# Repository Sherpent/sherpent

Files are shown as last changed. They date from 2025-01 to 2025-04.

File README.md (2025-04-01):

# Sherpent – Équipe #3
## S.H.E.R.P.E.N.T.
Système
Hybride
Exploratoire
Robotique
Prototypé
Et
Navigation
Tout-terrain

## 🌐 Projet: Sherpent – Robot Tout-Terrain Inspiré des Serpents

**Membres de l'équipe :**
- **Nathan Lachapelle** (lacn1101)
- **Émile Raymond** (raye1901)
- **Gabriel Grondin** (grog1401)
- **Mathieu Durand** (durm1207)
- **Renaud Gagnon** (gegr1618)
- **Maxime Boucher** (boom0704)

---

## 🔬 Contexte

Le projet Sherpent vise à concevoir et prototyper un véhicule tout-terrain s’inspirant des mouvements ondulatoires d’un serpent pour se déplacer. Les serpents utilisent leurs centaines de vertèbres et leurs muscles pour glisser sur diverses surfaces (‎terre, bois, vitre, sable, etc.), ce qui leur confère une capacité passe-partout. Ce type de locomotion est idéal pour des missions d’exploration terrestre ou pour évoluer dans des environnements extraterrestres hostiles.

L'étude des mouvements naturels de ces reptiles servira de base à la conception du robot Sherpent.

---

## 🎯 Objectifs du Projet

- **Robot articulé :** Le robot comprendra des joints articulés permettant des mouvements ondulatoires.
- **Actionneurs et capteurs :** Intégration d’actionneurs et de capteurs pour permettre un contrôle précis des mouvements.
- **Contrôle autonome :** Le robot fonctionnera de manière autonome, sans dépendance à des fils ou sources externes.
- **Langage Python :** Utilisation de Python pour une partie du code contrôlant le robot.
- **Applications potentielles :** Exploration terrestre ou exploration d’environnements extraterrestres.

---

## 📅 Livrables Attendues
Le projet sera développé en utilisant la méthodologie Agile, avec des livrables majeurs prévus à la fin de chaque sprint de 3 semaines :

| **Dates** | **Livrables Importants** |
|---|---|
| 22 janvier 2025 | Preuve de concept simple |
| 12 février 2025 | PCB montés et débuggés |
| 26 février 2025 | Contrôle du prototype |
| 26 mars 2025 | Phase de test du prototype |
| 11 avril 2025 | Rapport et prototype final |

---

## 📊 Analyse Sommaire de Faisabilité

**Compétences :** L’équipe possède une expertise multidisciplinaire en robotique :
- Compétences en électronique, mécanique et informatique.

**Ressources matérielles :** 
- Accès à du matériel et des installations telles que machines-outils, composants électroniques, et équipements de prototypage.

**Budget :** Les coûts supplémentaires seront partagés ou répartis selon les membres qui conserveront les matériaux au terme du projet.

**Conclusion :** Compte tenu des compétences, du matériel disponible et des ressources temporelles, l’équipe juge ce projet réalisable dans les délais impartis.

---

## 🔄 Planification Sommaire

1. **Organisation de l’équipe :**
   - Division en trois sections : électrique, mécanique, et informatique.
   - Collaboration interdépendante pour surmonter les embûches.

2. **Gestion de Projet :**
   - Utilisation de GitHub pour gérer le code, les fichiers, et la planification.
   - Réunion hebdomadaire chaque mercredi pour faire le point sur les avancements et problèmes.

3. **Développement Agile :**
   - Livrables précis à la fin de chaque sprint de 3 semaines.

---

## 🔧 Utilisation de GitHub

1. **Structure du Répertoire :**
   ```
   Sherpent/
   ├── elec/       # Fichiers électroniques (PCB, schémas, etc.)
   ├── mec/        # Fichiers mécaniques (CAD, modèles 3D, etc.)
   ├── code/       # Fichiers de code (Python, firmware, etc.)
   └── docs/       # Documentation et rapports
   ```

2. **Outils GitHub :**
   - **Issues :** Pour suivre les problèmes et défis.
   - **Projets :** Pour gérer les tâches et la planification Agile.
   - **Pull Requests :** Pour réviser et intégrer les changements.

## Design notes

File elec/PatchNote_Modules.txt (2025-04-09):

Patch notes

Pcb #1 État: Testé bat + moteurs
	Problème:
	Rien ne se passe quand no appuie sur le bouton.
	Avec USB: S'allume quand on pese sur le bouton (D25 manquante)
		Apres avoir été pluggé, le bouton fais allumer meme sur betterie mais stayon marche pas
	Avec safety bypass: Ya juste le stayon qui marche pas
	Mesures:
	Pin stayon tjrs à 0v
	
	Solution: 
		Changer le code
		Patch temporaire: Brancher usb pour sortir de over current protection
		Patch long terme: Betteries plus chargées? Bypasser le board bleu?
	C'est réglé.
	Problème: Board bleu laisse pas poweron après avoir branché la batterie. Il faut plugger usb ou short b-

PCB#2 État: Testé bat+moteurs

PCB#3 État: Testé bat + moteurs
	Problème: ne s'allume pas
	Mesures: 
		- Sortie du boost quand on pese sur le bouton: 2.8v
		- EN du boost tjrs a 0v
	Solution short en a 1 sur footprint de Q4
	Résultat: Fonctionne bien. À tester avec moteurs

PCB#4 État: Testé bat + moteurs
	Problème: Gate du power mosfet est tjrs triggered par tension sur vusb causée par le board bleu car il a une diode ordinaire et non une led
	Solution: Mettre une led sur D25 pour drop de tension plus haute (les autres pcbs l'ont deja)

PCB#5 État: En cours de soudure

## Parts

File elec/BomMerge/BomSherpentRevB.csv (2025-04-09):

Reference | Value | Footprint | Qty | DigiKey
BT1,BT2 | Battery_Cell | Connector_PinHeader_2.54mm:PinHeader_1x02_P2.54mm_Vertical | 2
C2,C15,C16 | 10u | Capacitor_SMD:C_0603_1608Metric_Pad1.08x0.95mm_HandSolder | 3 | 587-1256-1-ND
C3,C5,C21 | 100n | Capacitor_SMD:C_0603_1608Metric_Pad1.08x0.95mm_HandSolder | 3 | 311-1344-1-ND
C7,C8 | 100u | Capacitor_THT:CP_Radial_D5.0mm_P2.00mm | 2 | 732-8793-1-ND
C9,C10 | 1u | Capacitor_SMD:C_0603_1608Metric_Pad1.08x0.95mm_HandSolder | 2 | 587-1248-1-ND
C11 | 39n | Capacitor_SMD:C_0603_1608Metric_Pad1.08x0.95mm_HandSolder | 1 | 1276-2055-1-ND
C12 | 100p | Capacitor_SMD:C_0603_1608Metric_Pad1.08x0.95mm_HandSolder | 1 | 490-4771-1-ND
C13,C31,C32,C33 | 47u | Capacitor_SMD:C_0603_1608Metric_Pad1.08x0.95mm_HandSolder | 4 | 1276-1852-1-ND
C17,C26 | 0.1u | Capacitor_SMD:C_0603_1608Metric_Pad1.08x0.95mm_HandSolder | 2 | 311-1344-1-ND
C30 | 100u | Capacitor_SMD:C_0603_1608Metric_Pad1.08x0.95mm_HandSolder | 1 | 490-GRM21BR60G107ME11KCT-ND
D3,D4,D5,D13 | SS14 | Diode_SMD:D_SMA | 4 | SS14CT-ND
D7,D8,D9,D10,D11,D12,D16,D17,D18,D19 | WS2812B | LED_SMD:LED_WS2812B_PLCC4_5.0x5.0mm_P3.2mm | 10
F2,F3 | 10A | Fuse:Fuse_0603_1608Metric | 2 | 5923-0686F8000-01CT-ND
J1 | 2137160001 | 2137160001:MOLEX_2137160001 | 1 | 2073-USB4085-GF-ACT-ND
J2,J3,J4 | Conn_01x03_Socket | Connector_PinHeader_2.54mm:PinHeader_1x03_P2.54mm_Vertical | 3
JP7 | BOOT | Connector_PinHeader_2.54mm:PinHeader_1x02_P2.54mm_Vertical | 1
L1 | 1.2u | CMLE105T-2R2MS:IND_CMLE105T-1R0&slash_1R5&slash_2R2_CYN | 1 | 2037-CMLE105T-1R0MSCT-ND
Q1,Q5,Q6 | PMOS | Package_TO_SOT_SMD:SOT-223 | 3 | 3141-G170P06MCT-ND
Q2,Q3 | Q_NMOS_GSD | Package_TO_SOT_SMD:SOT-23 | 2 | 448-SN7002NH6433XTMA1CT-ND
R1,R3,R5,R6,R9,R16,R19,R20,R21,R22 | 10k | Resistor_SMD:R_0603_1608Metric | 10 | 311-5.10KHRCT-ND
R4,R10 | 5.1k | Resistor_SMD:R_0603_1608Metric | 2 | 311-5.10KHRCT-ND
R11 | 45.3k | Resistor_SMD:R_0603_1608Metric | 1 | 311-45.3KHRCT-ND
R12 | 357k | Resistor_SMD:R_0603_1608Metric | 1 | 311-357KHRCT-ND
R13 | 48.7k | Resistor_SMD:R_0603_1608Metric | 1 | 311-48.7KHRCT-ND
R17 | 0 | Resistor_SMD:R_0603_1608Metric | 1 | 311-0.0GRCT-ND
R27 | 50k | Resistor_SMD:R_0603_1608Metric | 1 | 13-RT0603BRD0750KLCT-ND
R28 | 100k 1% | Resistor_SMD:R_0603_1608Metric | 1 | P100KHCT-ND
SW1 | CT1102 | CT1102V3.15F100:CT1102V3.15F100 | 1 | 2449-CT1102V3.15F100-ND
SW2 | RESET | CS1213AGF160:SW_CS1213AG_CRS | 1 | 2449-CS1213AGF260CT-ND
SW3 | BOOT | CS1213AGF160:SW_CS1213AG_CRS | 1 | 2449-CS1213AGF260CT-ND
TP2 | VUSB | TestPoint:TestPoint_Loop_D2.54mm_Drill1.5mm_Beaded | 1
TP3 | RX | TestPoint:TestPoint_Loop_D2.54mm_Drill1.5mm_Beaded | 1
TP4 | 3v3 | TestPoint:TestPoint_Loop_D2.54mm_Drill1.5mm_Beaded | 1
TP5 | TX | TestPoint:TestPoint_Loop_D2.54mm_Drill1.5mm_Beaded | 1
TP6,TP8,TP16 | GND | TestPoint:TestPoint_Loop_D2.54mm_Drill1.5mm_Beaded | 3
TP7 | V_D | TestPoint:TestPoint_Loop_D2.54mm_Drill1.5mm_Beaded | 1
TP9 | NEO | TestPoint:TestPoint_Loop_D2.54mm_Drill1.5mm_Beaded | 1
TP10 | B+ | TestPoint:TestPoint_Loop_D2.54mm_Drill1.5mm_Beaded | 1
TP11 | B- | TestPoint:TestPoint_Loop_D2.54mm_Drill1.5mm_Beaded | 1
TP12 | PWM1 | TestPoint:TestPoint_Loop_D2.54mm_Drill1.5mm_Beaded | 1
TP13 | PWM2 | TestPoint:TestPoint_Loop_D2.54mm_Drill1.5mm_Beaded | 1
TP14,TP15 | V_B | TestPoint:TestPoint_Loop_D2.54mm_Drill1.5mm_Beaded | 2
TP17 | ST | TestPoint:TestPoint_Loop_D2.54mm_Drill1.5mm_Beaded | 1
U1 | TPD2EUSB30 | Package_TO_SOT_SMD:Texas_DRT-3 | 1 | 296-28153-1-ND
U2 | TPS61288LRQQR | TPS61288LRQQR:RQQ0011A-MFG | 1 | 296-TPS61288LRQQRCT-ND
U3 | LM66200DRLR | LM66200DRLR:SOT-5X3_DRL_TEX-L | 1 | 296-LM66200DRLRCT-ND
U4 | TP4056 | TP4056:TP4056-18650 | 1
U5 | LD1117S33TR_SOT223 | Package_TO_SOT_SMD:SOT-223-3_TabPin2 | 1 | 497-1241-1-ND
U8 | ESP32-C3-WROOM-02 | RF_Module:ESP32-C3-WROOM-02 | 1 | 1965-ESP32-C3-WROOM-02-N4CT-ND

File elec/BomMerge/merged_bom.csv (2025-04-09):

Reference | Value | Footprint | Qty | DigiKey | Datasheet
1C20 | 10u | Capacitor_SMD:C_0402_1005Metric_Pad0.74x0.62mm_HandSolder | 1 | 1276-1450-1-ND | ~
C13,C31,C32,C33 | 47u | Capacitor_SMD:C_0603_1608Metric_Pad1.08x0.95mm_HandSolder | 4 | 1276-1852-1-ND
C11 | 39n | Capacitor_SMD:C_0603_1608Metric_Pad1.08x0.95mm_HandSolder | 1 | 1276-2055-1-ND
R27 | 50k | Resistor_SMD:R_0603_1608Metric | 1 | 13-RT0603BRD0750KLCT-ND
1U7 | ESP32-C3 | ESP32_C3:QFN32_5X5_EXP-L | 1 | 1904-ESP32-C3FH4CT-ND | ESP32-C3
U8 | ESP32-C3-WROOM-02 | RF_Module:ESP32-C3-WROOM-02 | 1 | 1965-ESP32-C3-WROOM-02-N4CT-ND
L1 | 1.2u | CMLE105T-2R2MS:IND_CMLE105T-1R0&slash_1R5&slash_2R2_CYN | 1 | 2037-CMLE105T-1R0MSCT-ND
J1 | 2137160001 | 2137160001:MOLEX_2137160001 | 1 | 2073-USB4085-GF-ACT-ND
SW3 | BOOT | CS1213AGF160:SW_CS1213AG_CRS | 1 | 2449-CS1213AGF260CT-ND
SW1 | CT1102 | CT1102V3.15F100:CT1102V3.15F100 | 1 | 2449-CT1102V3.15F100-ND
U1 | TPD2EUSB30 | Package_TO_SOT_SMD:Texas_DRT-3 | 1 | 296-28153-1-ND
U3 | LM66200DRLR | LM66200DRLR:SOT-5X3_DRL_TEX-L | 1 | 296-LM66200DRLRCT-ND
U2 | TPS61288LRQQR | TPS61288LRQQR:RQQ0011A-MFG | 1 | 296-TPS61288LRQQRCT-ND
1R21,R26 | 0 | Resistor_SMD:R_0603_1608Metric | 2 | 311-0.0GRCT-ND | ~
1C3,C5,C17,C21,C24 | 100n | Capacitor_SMD:C_0603_1608Metric_Pad1.08x0.95mm_HandSolder | 5 | 311-1344-1-ND | ~
1C23 | 100n | Capacitor_SMD:C_0402_1005Metric_Pad0.74x0.62mm_HandSolder | 1 | 311-3566-1-ND | ~
R12 | 357k | Resistor_SMD:R_0603_1608Metric | 1 | 311-357KHRCT-ND
R11 | 45.3k | Resistor_SMD:R_0603_1608Metric | 1 | 311-45.3KHRCT-ND
R13 | 48.7k | Resistor_SMD:R_0603_1608Metric | 1 | 311-48.7KHRCT-ND
R1,R3,R5,R6,R9,R16,R19,R20,R21,R22 | 10k | Resistor_SMD:R_0603_1608Metric | 10 | 311-5.10KHRCT-ND
Q1,Q5,Q6 | PMOS | Package_TO_SOT_SMD:SOT-223 | 3 | 3141-G170P06MCT-ND
Q2,Q3 | Q_NMOS_GSD | Package_TO_SOT_SMD:SOT-23 | 2 | 448-SN7002NH6433XTMA1CT-ND
1C25 | 1u | Capacitor_SMD:C_0402_1005Metric_Pad0.74x0.62mm_HandSolder | 1 | 490-10024-1-ND | ~
1L2 | 2.7n | Inductor_SMD:L_0402_1005Metric_Pad0.77x0.64mm_HandSolder | 1 | 490-1078-1-ND | ~
1L3 | 2n | Inductor_SMD:L_0402_1005Metric_Pad0.77x0.64mm_HandSolder | 1 | 490-15076-1-ND | ~
1C6 | 2.2u | Capacitor_SMD:C_0603_1608Metric_Pad1.08x0.95mm_HandSolder | 1 | 490-4520-1-ND | ~
C12 | 100p | Capacitor_SMD:C_0603_1608Metric_Pad1.08x0.95mm_HandSolder | 1 | 490-4771-1-ND
1C19,C26 | 10n | Capacitor_SMD:C_0603_1608Metric_Pad1.08x0.95mm_HandSolder | 2 | 490-4781-1-ND | ~
1C16,C18 | 1.8p | Capacitor_SMD:C_0402_1005Metric_Pad0.74x0.62mm_HandSolder | 2 | 490-6215-1-ND | ~
1C27,C28 | 15p | Capacitor_SMD:C_0402_1005Metric_Pad0.74x0.62mm_HandSolder | 2 | 490-8080-1-ND | ~
C30 | 100u | Capacitor_SMD:C_0603_1608Metric_Pad1.08x0.95mm_HandSolder | 1 | 490-GRM21BR60G107ME11KCT-ND
U5 | LD1117S33TR_SOT223 | Package_TO_SOT_SMD:SOT-223-3_TabPin2 | 1 | 497-1241-1-ND
1Y1 | 40MHz | 830059627:SMD_059627_WRE-L | 1 | 535-15013-1-ND | ~
1C9,C10,C22,C29 | 1u | Capacitor_SMD:C_0603_1608Metric_Pad1.08x0.95mm_HandSolder | 4 | 587-1248-1-ND | ~
C2,C15,C16 | 10u | Capacitor_SMD:C_0603_1608Metric_Pad1.08x0.95mm_HandSolder | 3 | 587-1256-1-ND
1F2,F3 | 10A | Fuse:Fuse_0603_1608Metric | 2 | 5923-0686F8000-01CT-ND | ~
1C7,C8 | 100u | Capacitor_THT:CP_Radial_D5.0mm_P2.00mm | 2 | 732-8793-1-ND | ~
1R24 | 0 | Resistor_SMD:R_0402_1005Metric_Pad0.72x0.64mm_HandSolder | 1 | P0.0JCT-ND | ~
R28 | 100k 1% | Resistor_SMD:R_0603_1608Metric | 1 | P100KHCT-ND
D3,D4,D5,D13 | SS14 | Diode_SMD:D_SMA | 4 | SS14CT-ND
1D1,D2,D25 | D_Schottky | LED_SMD:LED_0603_1608Metric_Pad1.05x0.95mm_HandSolder | 3 | TSS54URGGCT-ND | ~
D7,D8,D9,D10,D11,D12,D16,D17,D18,D19 | WS2812B | LED_SMD:LED_WS2812B_PLCC4_5.0x5.0mm_P3.2mm | 10

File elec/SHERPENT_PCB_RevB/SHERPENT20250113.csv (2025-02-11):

Id | Designator | Footprint | Quantity | Designation | Supplier and ref
1 | R24 | R_0402_1005Metric_Pad0.72x0.64mm_HandSolder | 1 | 0
2 | D9,D8,D17,D10,D16,D18,D19,D12,D7,D11 | LED_WS2812B_PLCC4_5.0x5.0mm_P3.2mm | 10 | WS2812B
3 | C12 | C_0603_1608Metric_Pad1.08x0.95mm_HandSolder | 1 | 100p
4 | D2,D25,D1 | LED_0603_1608Metric_Pad1.05x0.95mm_HandSolder | 3 | D_Schottky
5 | R9,R1,R20,R17,R22,R5,R16,R6,R3,R25 | R_0603_1608Metric | 10 | 10k
6 | Q4,Q2 | SOT-23 | 2 | PMOS
7 | D3,D6 | LED_0603_1608Metric_Pad1.05x0.95mm_HandSolder | 2 | LED
8 | C25 | C_0402_1005Metric_Pad0.74x0.62mm_HandSolder | 1 | 1u
9 | C3,C14,C21,C17,C24 | C_0603_1608Metric_Pad1.08x0.95mm_HandSolder | 5 | 100n
10 | C4,C1 | C_0603_1608Metric_Pad1.08x0.95mm_HandSolder | 2 | 4.7u
11 | C5 | C_0603_1608Metric_Pad1.08x0.95mm_HandSolder | 1 | 100nf
12 | C29,C10,C9,C22 | C_0603_1608Metric_Pad1.08x0.95mm_HandSolder | 4 | 1u
13 | R2,R14 | R_0603_1608Metric | 2 | 100k
14 | R18,R26,R21 | R_0603_1608Metric | 3 | 0
15 | C16,C18 | C_0402_1005Metric_Pad0.74x0.62mm_HandSolder | 2 | 1.8p
16 | C23 | C_0402_1005Metric_Pad0.74x0.62mm_HandSolder | 1 | 100n
17 | TP1 | TestPoint_Loop_D2.54mm_Drill1.5mm_Beaded | 1 | VBATT
18 | J4,J2,J3 | PinHeader_1x03_P2.54mm_Vertical | 3 | Conn_01x03_Socket
19 | R10,R4 | R_0603_1608Metric | 2 | 5.1k
20 | L2 | L_0402_1005Metric_Pad0.77x0.64mm_HandSolder | 1 | 2.7n
21 | R13 | R_0603_1608Metric | 1 | 48.7k
22 | R11 | R_0603_1608Metric | 1 | 45.3k
23 | TP7,NEO-END1,TP4,TP2 | TestPoint_Loop_D2.54mm_Drill1.5mm_Beaded | 4 | TestPoint
24 | C11 | C_0603_1608Metric_Pad1.08x0.95mm_HandSolder | 1 | 39n
25 | F3,F2 | Fuse_0603_1608Metric | 2 | 10A
26 | C20 | C_0402_1005Metric_Pad0.74x0.62mm_HandSolder | 1 | 10u
27 | L3 | L_0402_1005Metric_Pad0.77x0.64mm_HandSolder | 1 | 2n
28 | C30 | C_0603_1608Metric_Pad1.08x0.95mm_HandSolder | 1 | 100u
29 | U6 | AN034_ANTENNA | 1 | AN034_ANTENNA
30 | C8,C7 | CP_Radial_D5.0mm_P2.00mm | 2 | 100u
31 | C28,C27 | C_0402_1005Metric_Pad0.74x0.62mm_HandSolder | 2 | 15p
32 | Q3,Q1 | SOT-23 | 2 | NMOS
33 | C15,C2 | C_0603_1608Metric_Pad1.08x0.95mm_HandSolder | 2 | 10u
34 | D28,D4 | R_0603_1608Metric_Pad0.98x0.95mm_HandSolder | 2 | D_Zener
35 | R7 | R_0603_1608Metric | 1 | 470
36 | C26,C19 | C_0603_1608Metric_Pad1.08x0.95mm_HandSolder | 2 | 10n
37 | BT1,BT2 | PinHeader_1x02_P2.54mm_Vertical | 2 | Battery_Cell
38 | D29 | D_0603_1608Metric_Pad1.05x0.95mm_HandSolder | 1 | D
39 | U2 | RQQ0011A-MFG | 1 | TPS61288LRQQR
40 | R28 | R_0603_1608Metric | 1 | 100k 1%
41 | R12 | R_0603_1608Metric | 1 | 357k
42 | R23 | R_0603_1608Metric | 1 | 130
43 | U5 | SOT-223-3_TabPin2 | 1 | LD1117S33TR_SOT223
44 | C13 | C_0603_1608Metric_Pad1.08x0.95mm_HandSolder | 1 | 47u
45 | C6 | C_0603_1608Metric_Pad1.08x0.95mm_HandSolder | 1 | 2.2u
46 | SW2 | SW_CS1213AG_CRS | 1 | SW_Push
47 | R8 | R_0603_1608Metric | 1 | 2k
48 | J1 | MOLEX_2137160001 | 1 | 2137160001
49 | R27 | R_0603_1608Metric | 1 | 50k
50 | JP19 | TestPoint_2Pads_Pitch2.54mm_Drill0.8mm | 1 | Jumper_2_Bridged
51 | Y1 | SMD_059627_WRE-L | 1 | 40MHz
52 | L1 | L_0603_1608Metric | 1 | 1.2u
53 | U7 | QFN32_5X5_EXP-L | 1 | ESP32-C3
54 | U1 | SOT95P280X145-5N | 1 | MCP73831T-2ACI_OT
55 | U4 | TP4056-18650 | 1 | TP4056
56 | SW1 | CT1102V3.15F100 | 1 | CT1102
57 | D27,D26 | SOT-23 | 2 | BAV99

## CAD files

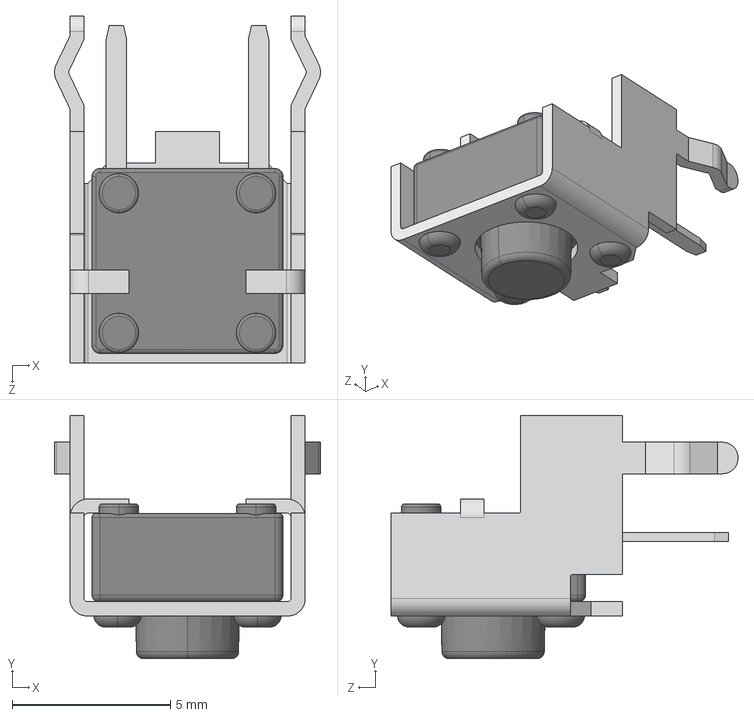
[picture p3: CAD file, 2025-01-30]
elec/SHERPENT_PCB_RevB/Librairie/CT1102V3.15F100/CT1102V3.85F160.stp
8.42 x 7.70 x 11.0 mm

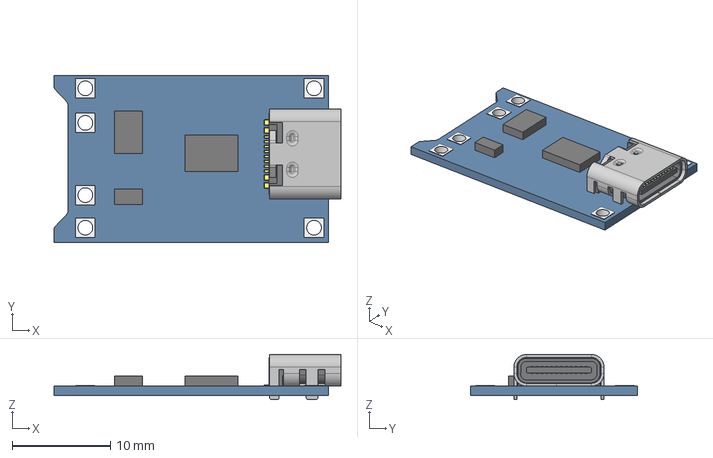
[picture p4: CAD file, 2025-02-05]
elec/SHERPENT_PCB_RevB/Librairie/TP4056/TP4056--3DModel-STEP-684600.STEP
29.3 x 17.0 x 4.60 mm

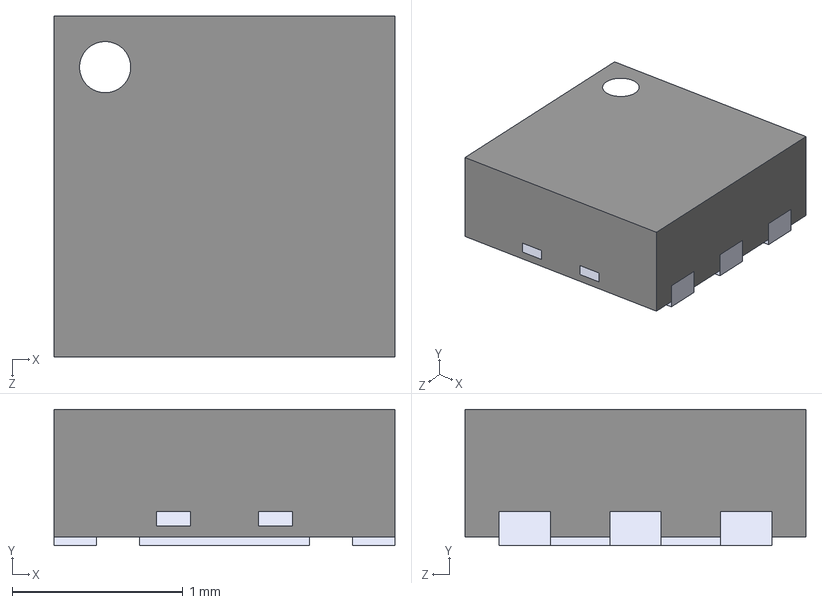
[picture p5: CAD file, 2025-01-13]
elec/SHERPENT_PCB_RevB/Librairie/TPS7A2633DRVR/TPS7A2633DRVR.step
2.00 x 0.8 x 2.00 mm

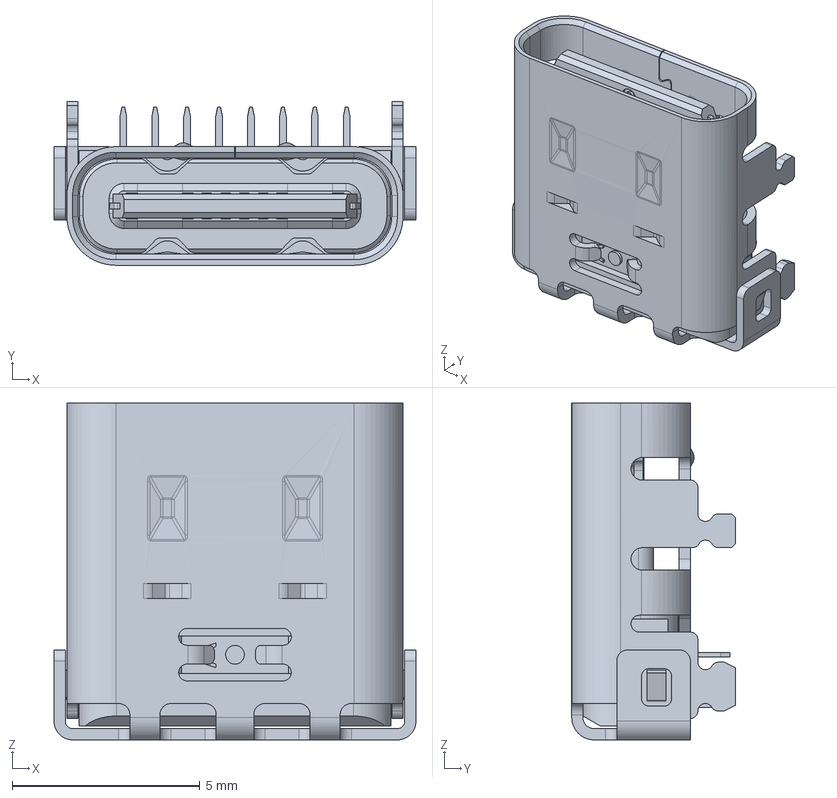
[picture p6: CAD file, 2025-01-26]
elec/SHERPENT_PCB_RevB/Librairie/2137160001/2137160001.stp
9.64 x 4.36 x 8.97 mm

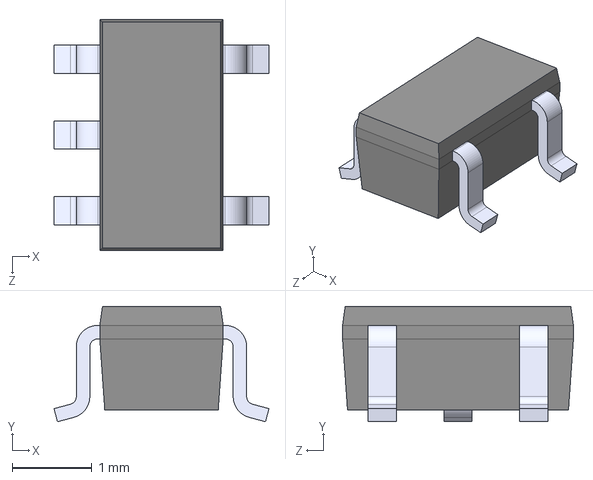
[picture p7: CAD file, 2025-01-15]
elec/SHERPENT_PCB_RevB/Librairie/MCP73831T_2ACI_OT/MCP73831T-2ACI_OT.step
2.70 x 1.45 x 2.90 mm

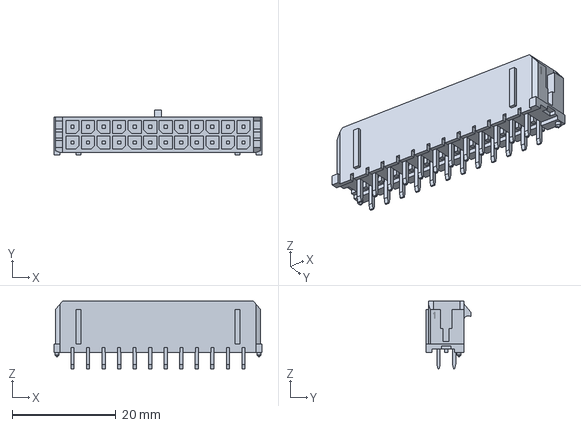
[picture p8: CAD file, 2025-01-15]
elec/SHERPENT_PCB_RevB/Librairie/MOLEX_430452428/0430452428.stp
40.1 x 8.77 x 13.1 mm

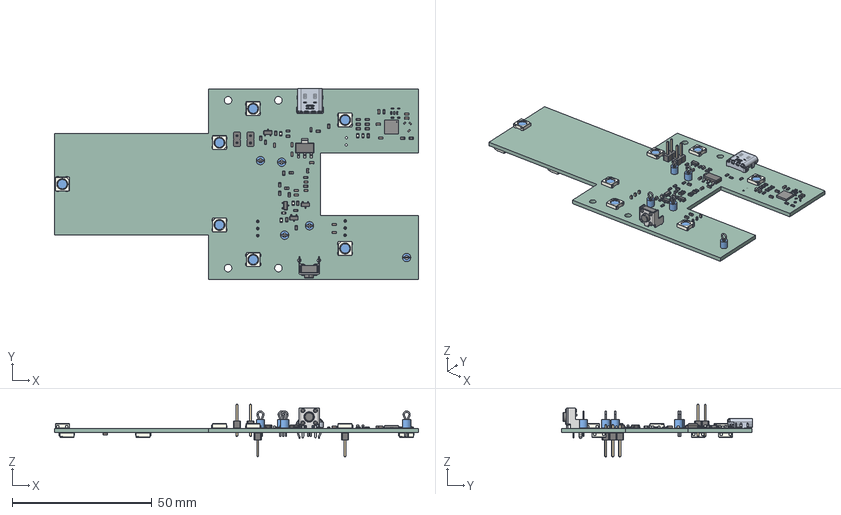
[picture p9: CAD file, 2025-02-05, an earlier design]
elec/SHERPENT_PCB_RevA/SHERPENT20250113_3.step
130.2 x 68.3 x 18.8 mm
R_0402_1005Metric
LED_WS2812B_PLCC4_50x50mm_P32mm x 13
C_0603_1608Metric x 20
LED_0603_1608Metric x 6
R_0603_1608Metric x 26
SOT_23 x 4
C_0402_1005Metric x 7
Fuse_0603_1608Metric
TestPoint_Loop_D2_54mm_Drill1_5mm_Beaded_cp x 5
L_0402_1005Metric x 2
PinHeader_1x02_P254mm_Vertical x 2
SOT_223
L_0603_1608Metric
ESP32-C3FH4
CT1102V3.85F160
PinHeader_1x03_P254mm_Vertical x 2
_autosave-SHERPENT20250113_PCB

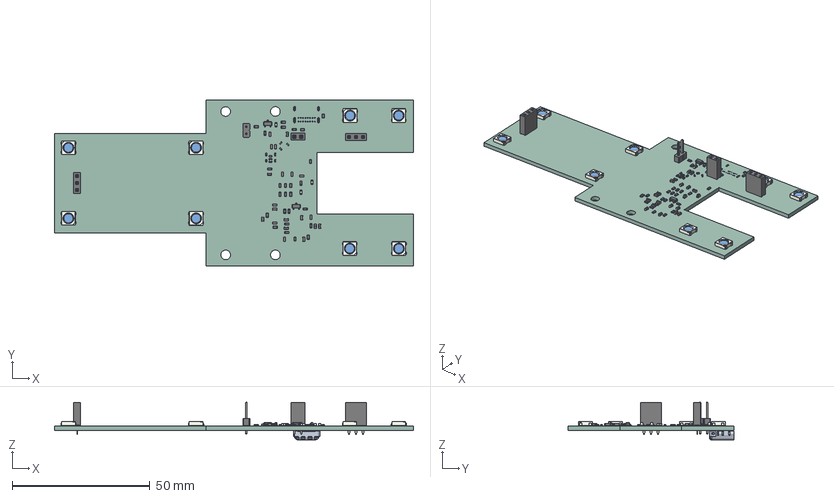
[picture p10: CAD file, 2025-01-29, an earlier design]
elec/SHERPENT_PCB_RevA/SHERPENT20250113_2.step
130.2 x 60.3 x 13.7 mm
R_0402_1005Metric
D_0603
LED_WS2812B_PLCC4_50x50mm_P32mm x 8
C_0603_1608Metric x 18
R_0603_1608Metric x 33
LED_0603_1608Metric x 3
C_0402_1005Metric x 7
Fuse_0603_1608Metric
L_0402_1005Metric x 2
SOT_23 x 2
PinHeader_1x02_P254mm_Vertical
PinSocket_1x03_P2.54mm_Vertical x 2
PinSocket_1x02_P2.54mm_Vertical
L_0603_1608Metric
SHERPENT20250113_PCB

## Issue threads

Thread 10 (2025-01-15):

Commander les pieces pour les PCB supplémentaires

gabgron, 2025-01-15:

Pinox64, 2025-04-09:
Commander pour faire 5 revB ou 2 revA (si les pcb arrivent trop tard)
Mettre les 2 boms ensemble et prendre les quantités les plus hautes (ne pas additionner)

Closed 2025-04-10.

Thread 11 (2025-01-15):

Magasinner les servos

gabgron, 2025-01-15:
Vérifier si l'école fournit des servos. Si non en acheter

gabgron, 2025-01-15:
ces servos la semblent pas-pire [lien](https://ca.robotshop.com/products/mg995-micro-servo-motor-rc-servo-20-kg-metal-gear-servo-4x) on va attndre de voir si l'ecole nous en prete

gabgron, 2025-01-15:
on va commeder sur la [lien](https://www.amazon.com/4-Pack-MG996R-Torque-Digital-Helicopter/dp/B0BMM1G74B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)

Closed 2025-01-15.

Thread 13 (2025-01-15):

Faire approver les battrie

gabgron, 2025-01-15:

maximeboucher5, 2025-01-31:
Alexandre Tessier nous a donner le go. Il va falloir faire un plan de test/procédure et avoir une autre rencontre avec lui. Le circuit à passer la "validation"

Closed 2025-01-31.

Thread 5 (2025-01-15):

Printer les bracket pour relier les servo

gabgron, 2025-01-15:

gabgron, 2025-01-15:
premier proto de fait, mais les brakets de fittent pas avec les servos qu'on a

nathan477, 2025-01-15:
Pour faire fitter les servo, on va limer les brackets (éviter de reprint les brackets)

Closed 2025-01-22.

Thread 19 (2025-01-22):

Livrer le suivi de projet avec tableau de bord (29 janvier)

nathan477, 2025-01-22:
Scrum tenu pour faire le suivi de projet (qui a fait quoi durant le dernier sprint). Tableau de bord à déposer (maximum la veille de la période de projet) pour animer la rencontre (1 page max).
Requis :
- Nom du projet et d'équipe
- Photos des membres avec leur noms et responsabilités
- Période couverte pour les activités du tableau de bord
- Objectif du projet (sommaire, maximum deux lignes)
- Suivi de projet (Burndown chart (chart, release), tâches accomplie durant la semaine, tâche à faire next week)
- Sommaire des heures de la semaine et en moyenne faites par chaque membre
- Suivi des risques avec les moyens pour les annuler/atténuer
- Problèmes rencontrés
- Points à aborder avec le superviseur de projet

nathan477, 2025-01-22:
Le template du document de suivi de projet est disponible dans le Teams sous Fichiers, General, Documents_livrable, Suivi_de_projet_template

Closed 2025-01-29.

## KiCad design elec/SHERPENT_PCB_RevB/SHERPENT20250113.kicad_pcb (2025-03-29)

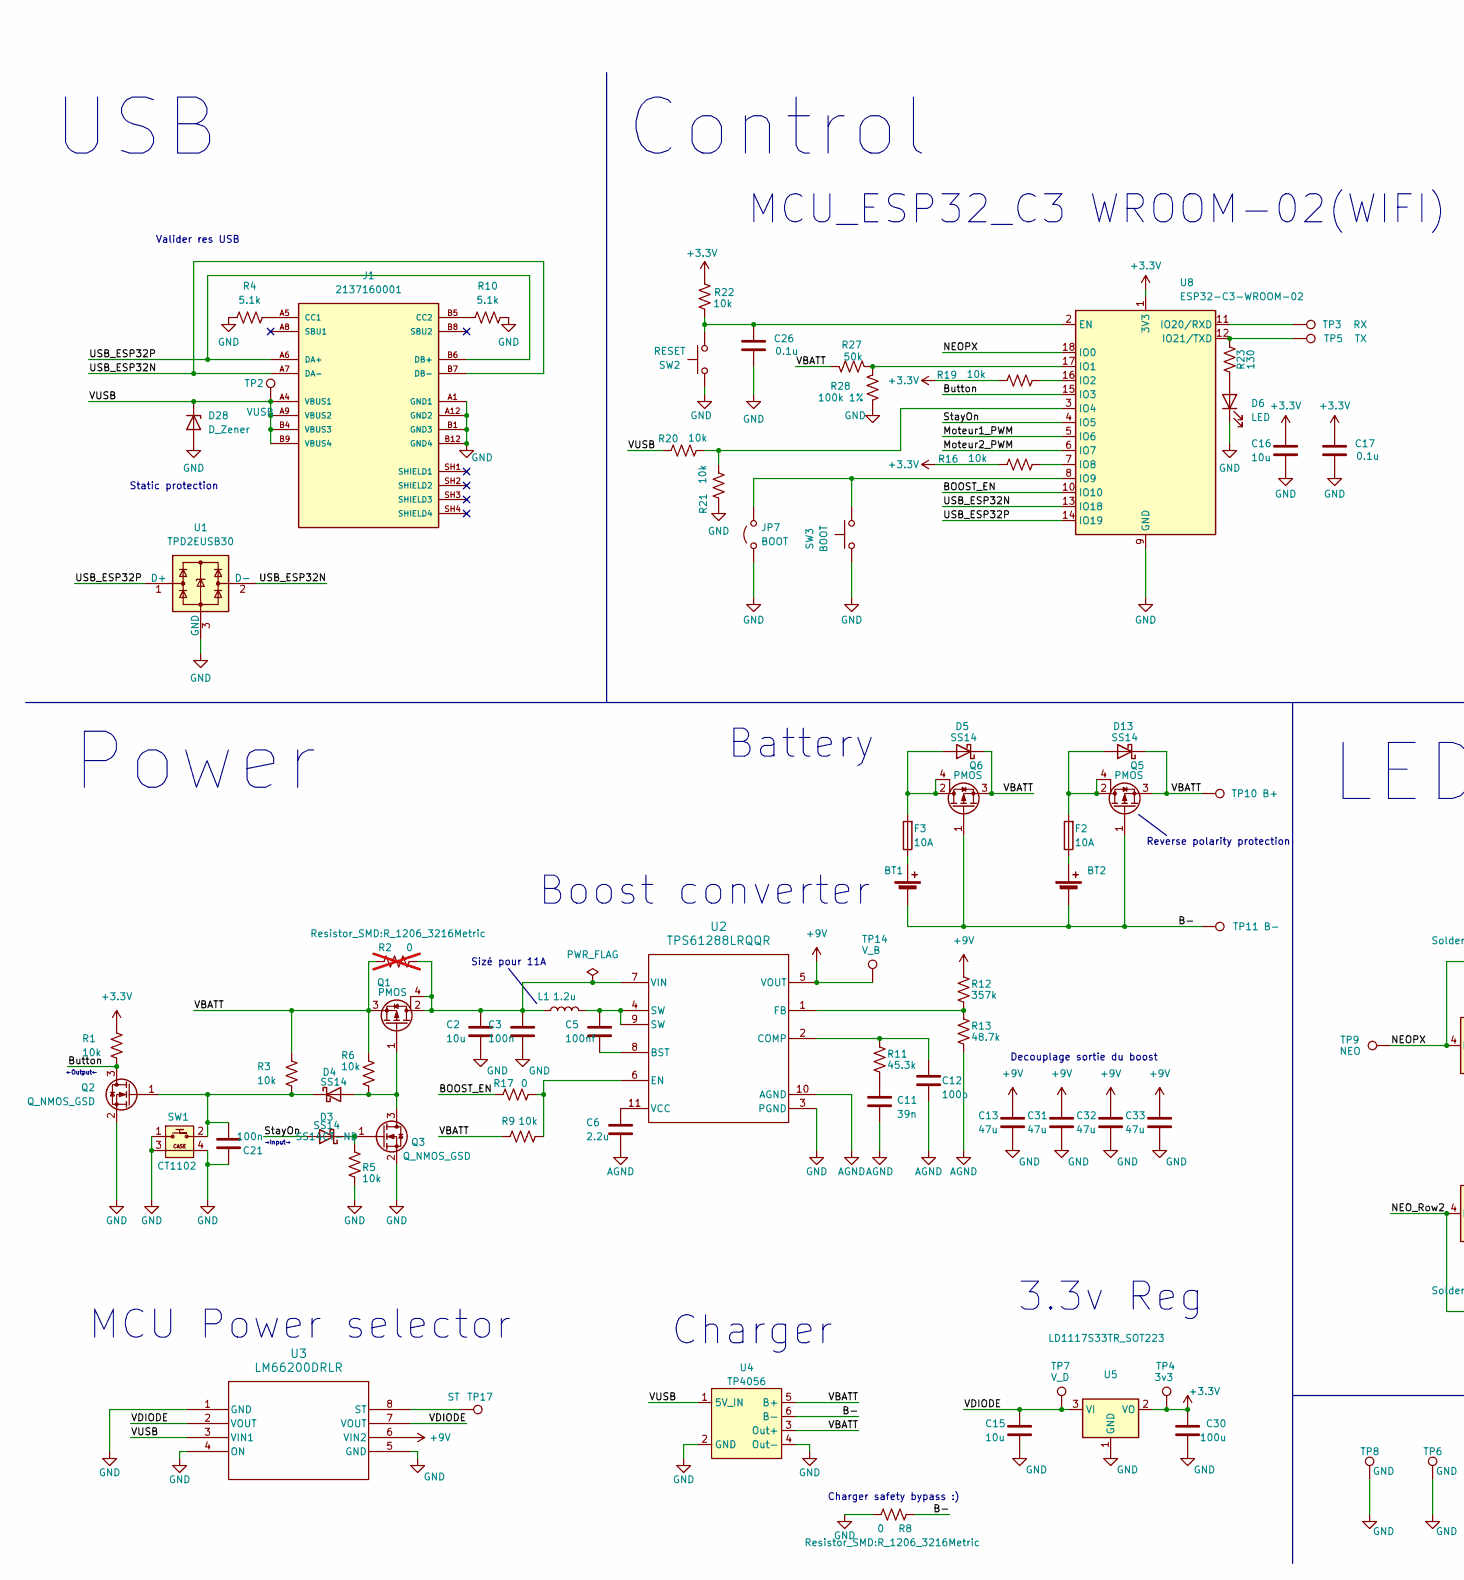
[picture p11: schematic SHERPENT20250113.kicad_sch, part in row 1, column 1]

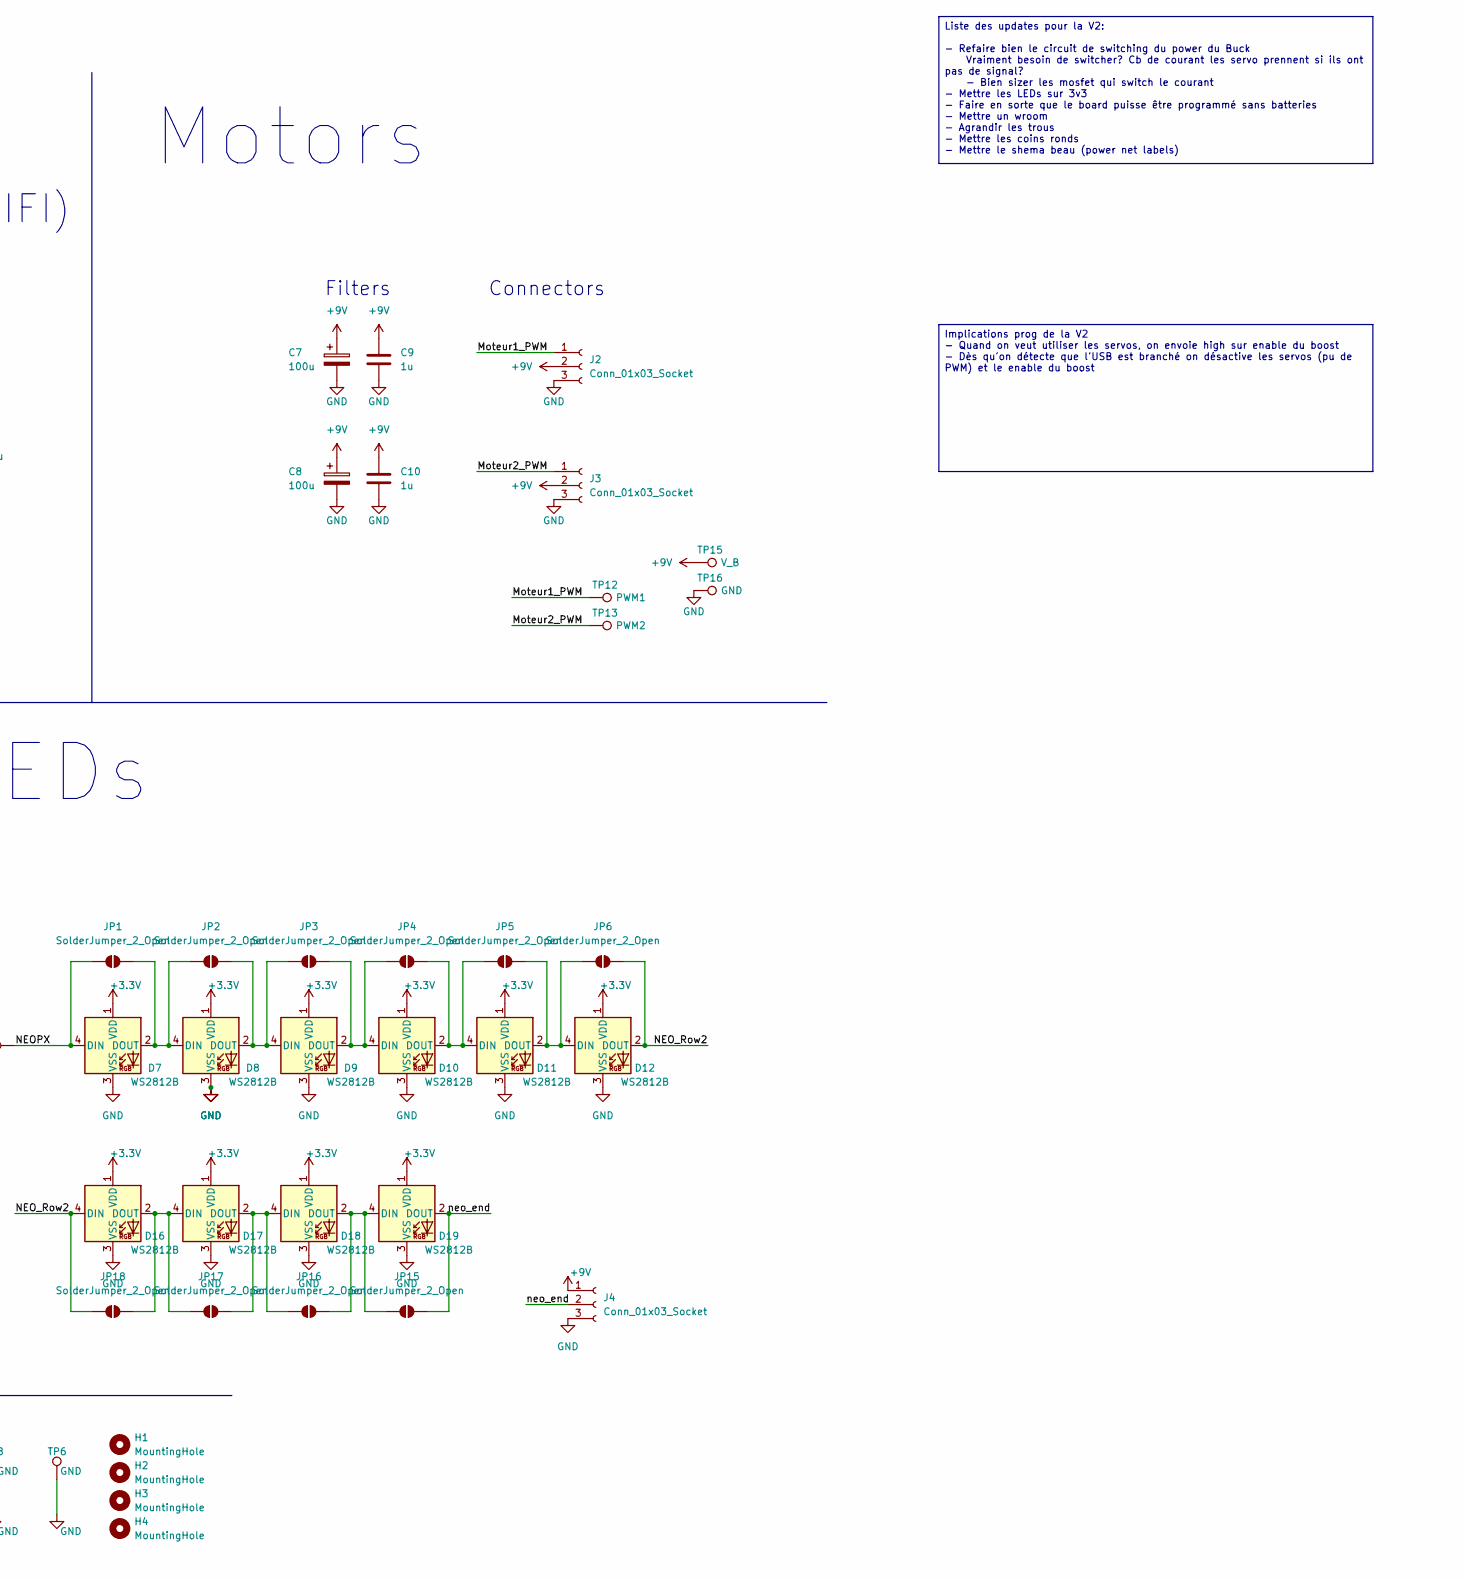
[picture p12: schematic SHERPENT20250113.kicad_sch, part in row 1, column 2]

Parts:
BT1, BT2: Battery_Cell; PinHeader_1x02_P2.54mm_Vertical
C2, C15, C16: 10u; C_0603_1608Metric_Pad1.08x0.95mm_HandSolder
C3, C21: 100n; C_0603_1608Metric_Pad1.08x0.95mm_HandSolder
C5: 100nf; C_0603_1608Metric_Pad1.08x0.95mm_HandSolder
C6: 2.2u; C_0603_1608Metric_Pad1.08x0.95mm_HandSolder
C7, C8: 100u; CP_Radial_D5.0mm_P2.00mm
C9, C10: 1u; C_0603_1608Metric_Pad1.08x0.95mm_HandSolder
C11: 39n; C_0603_1608Metric_Pad1.08x0.95mm_HandSolder
C12: 100p; C_0603_1608Metric_Pad1.08x0.95mm_HandSolder
C13, C31, C32, C33: 47u; C_0603_1608Metric_Pad1.08x0.95mm_HandSolder
C17, C26: 0.1u; C_0603_1608Metric_Pad1.08x0.95mm_HandSolder
C30: 100u; C_0603_1608Metric_Pad1.08x0.95mm_HandSolder
D3, D4, D5, D13: SS14; D_SMA; DigiKey SS14CT-ND
D6: LED; LED_0603_1608Metric_Pad1.05x0.95mm_HandSolder
D7: WS2812B; LED_WS2812B_PLCC4_5.0x5.0mm_P3.2mm; MPN WS2812B-5050
D8, D9, D10, D11, D12, D16, D17, D18, D19: WS2812B; LED_WS2812B_PLCC4_5.0x5.0mm_P3.2mm
D28: D_Zener; R_0603_1608Metric_Pad0.98x0.95mm_HandSolder
F2, F3: 10A; Fuse_0603_1608Metric
H1, H2, H3, H4: MountingHole; MountingHole_3.2mm_M3
J1: 2137160001; MOLEX_2137160001; PARTREV B
J2, J3, J4: Conn_01x03_Socket; PinHeader_1x03_P2.54mm_Vertical
JP1, JP2, JP3, JP4, JP5, JP6, JP15, JP16, JP17, JP18: SolderJumper_2_Open; SolderJumper-2_P1.3mm_Open_TrianglePad1.0x1.5mm
JP7: BOOT; PinHeader_1x02_P2.54mm_Vertical
L1: 1.2u; IND_CMLE105T-1R0&slash_1R5&slash_2R2_CYN; DigiKey 2037-CMLE105T-1R0MSCT-ND
Q1, Q5, Q6: PMOS; SOT-223; MPN NTF6P02T3G; DigiKey 3141-G170P06MCT-ND
Q2, Q3: Q_NMOS_GSD; SOT-23; MPN SN7002NH6433XTMA1; DigiKey 448-SN7002NH6433XTMA1CT-ND
R1, R3, R5, R6, R9, R16, R19, R20, R21, R22: 10k; R_0603_1608Metric
R2: 0; R_1206_3216Metric; not fitted
R4, R10: 5.1k; R_0603_1608Metric
R8: 0; R_1206_3216Metric
R11: 45.3k; R_0603_1608Metric
R12: 357k; R_0603_1608Metric
R13: 48.7k; R_0603_1608Metric
R17: 0; R_0603_1608Metric
R23: 130; R_0603_1608Metric
R27: 50k; R_0603_1608Metric
R28: 100k 1%; R_0603_1608Metric
SW1: CT1102; CT1102V3.15F100
SW2: RESET; SW_CS1213AG_CRS
SW3: BOOT; SW_CS1213AG_CRS
TP2: VUSB; TestPoint_Loop_D2.54mm_Drill1.5mm_Beaded
TP3: RX; TestPoint_Loop_D2.54mm_Drill1.5mm_Beaded
TP4: 3v3; TestPoint_Loop_D2.54mm_Drill1.5mm_Beaded
TP5: TX; TestPoint_Loop_D2.54mm_Drill1.5mm_Beaded
TP6, TP8, TP16: GND; TestPoint_Loop_D2.54mm_Drill1.5mm_Beaded
TP7: V_D; TestPoint_Loop_D2.54mm_Drill1.5mm_Beaded
TP9: NEO; TestPoint_Loop_D2.54mm_Drill1.5mm_Beaded
TP10: B+; TestPoint_Loop_D2.54mm_Drill1.5mm_Beaded
TP11: B-; TestPoint_Loop_D2.54mm_Drill1.5mm_Beaded
TP12: PWM1; TestPoint_Loop_D2.54mm_Drill1.5mm_Beaded
TP13: PWM2; TestPoint_Loop_D2.54mm_Drill1.5mm_Beaded
TP14, TP15: V_B; TestPoint_Loop_D2.54mm_Drill1.5mm_Beaded
TP17: ST; TestPoint_Loop_D2.54mm_Drill1.5mm_Beaded
U1: TPD2EUSB30; Texas_DRT-3
U2: TPS61288LRQQR; RQQ0011A-MFG; MPN TPS61288LRQQR; DigiKey 296-TPS61288LRQQRCT-ND
U3: LM66200DRLR; SOT-5X3_DRL_TEX-L
U4: TP4056; TP4056-18650
U5: LD1117S33TR_SOT223; SOT-223-3_TabPin2
U8: ESP32-C3-WROOM-02

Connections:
+3.3V: C16.1, C17.1, C30.2, D7.1 (VDD), D8.1 (VDD), D9.1 (VDD), D10.1 (VDD), D11.1 (VDD), D12.1 (VDD), D16.1 (VDD), D17.1 (VDD), D18.1 (VDD), D19.1 (VDD), R1.1, R16.1, R19.1, R22.2, TP4.1, U5.2 (VO), U8.1 (3V3)
+9V: C7.1, C8.1, C9.1, C10.1, C13.1, C31.1, C32.1, C33.1, J2.2, J3.2, J4.1, R12.1, TP14.1, TP15.1, U2.5 (VOUT), U3.6 (VIN2)
/B-: BT1.2 (-), BT2.2 (-), Q5.1 (G), Q6.1 (G), R8.1, TP11.1, U4.6 (B-)
/BOOST_EN: R17.1, U8.10 (IO10)
/Button: Q2.3 (D), R1.2, U8.15 (IO3)
/Moteur1_PWM: J2.1, TP12.1, U8.5 (IO6)
/Moteur2_PWM: J3.1, TP13.1, U8.6 (IO7)
/NEOPX: D7.4 (DIN), JP1.1 (A), TP9.1, U8.18 (IO0)
/NEO_Row2: D12.2 (DOUT), D16.4 (DIN), JP6.2 (B), JP18.1 (A)
/StayOn: D3.2 (A), U8.4 (IO5)
/USB_ESP32N: J1.A7 (DA-), J1.B7 (DB-), U1.2 (D-), U8.13 (IO18)
/USB_ESP32P: J1.A6 (DA+), J1.B6 (DB+), U1.1 (D+), U8.14 (IO19)
/VBATT: D5.1 (K), D13.1 (K), Q1.3 (S), Q5.3 (S), Q6.3 (S), R2.1, R3.1, R6.1, R9.1, R27.2, TP10.1, U4.3 (Out+), U4.5 (B+)
/VDIODE: C15.1, TP7.1, U3.2 (VOUT), U3.7 (VOUT), U5.3 (VI)
/VUSB: D28.1 (K), J1.A4 (VBUS1), J1.A9 (VBUS2), J1.B4 (VBUS3), J1.B9 (VBUS4), R20.1, TP2.1, U3.3 (VIN1), U4.1 (5V_IN)
/neo_end: D19.2 (DOUT), J4.2, JP15.2 (B)
AGND: C6.2, C11.2, C12.2, R13.2, U2.10 (AGND)
GND: C2.2, C3.2, C7.2, C8.2, C9.2, C10.2, C13.2, C15.2, C16.2, C17.2, C21.1, C26.2, C30.1, C31.2, C32.2, C33.2, D6.1 (K), D7.3 (VSS), D8.3 (VSS), D9.3 (VSS), D10.3 (VSS), D11.3 (VSS), D12.3 (VSS), D16.3 (VSS), D17.3 (VSS), D18.3 (VSS), D19.3 (VSS), D28.2 (A), J1.A1 (GND1), J1.A12 (GND2), J1.B1 (GND3), J1.B12 (GND4), J2.3, J3.3, J4.3, JP7.1 (A), Q2.2 (S), Q3.2 (S), R4.1, R5.2, R8.2, R10.2, R21.1, R28.1, SW1.1, SW1.3, SW1.4, SW2.1, SW3.1, TP6.1, TP8.1, TP16.1, U1.3 (GND), U2.3 (PGND), U3.1 (GND), U3.4 (ON), U3.5 (GND), U4.2 (GND), U4.4 (Out-), U5.1 (GND), U8.9 (GND), U8.19 (GND)
unnamed: BT1.1 (+), F3.1
unnamed: BT2.1 (+), F2.1
unnamed: C5.1, L1.2, U2.4 (SW), U2.9 (SW)
unnamed: C11.1, R11.2
unnamed: D3.1 (K), Q3.1 (G), R5.1
unnamed: D4.2 (A), Q1.1 (G), Q3.3 (D), R6.2
unnamed: C21.2, D4.1 (K), Q2.1 (G), R3.2, SW1.2
unnamed: D5.2 (A), F3.2, Q6.2 (D), Q6.4 (D)
unnamed: D6.2 (A), R23.1
unnamed: D7.2 (DOUT), D8.4 (DIN), JP1.2 (B), JP2.1 (A)
unnamed: D8.2 (DOUT), D9.4 (DIN), JP2.2 (B), JP3.1 (A)
unnamed: D9.2 (DOUT), D10.4 (DIN), JP3.2 (B), JP4.1 (A)
unnamed: D10.2 (DOUT), D11.4 (DIN), JP4.2 (B), JP5.1 (A)
unnamed: D11.2 (DOUT), D12.4 (DIN), JP5.2 (B), JP6.1 (A)
unnamed: D13.2 (A), F2.2, Q5.2 (D), Q5.4 (D)
unnamed: D16.2 (DOUT), D17.4 (DIN), JP17.1 (A), JP18.2 (B)
unnamed: D17.2 (DOUT), D18.4 (DIN), JP16.1 (A), JP17.2 (B)
unnamed: D18.2 (DOUT), D19.4 (DIN), JP15.1 (A), JP16.2 (B)
unnamed: J1.A5 (CC1), R4.2
unnamed: J1.B5 (CC2), R10.1
unnamed: JP7.2 (B), SW3.2, U8.8 (IO9)
unnamed: C5.2, U2.8 (BST)
unnamed: C12.1, R11.1, U2.2 (COMP)
unnamed: R9.2, R17.2, U2.6 (EN)
unnamed: R12.2, R13.1, U2.1 (FB)
unnamed: C6.1, U2.11 (VCC)
unnamed: C2.1, C3.1, L1.1, Q1.2 (D), Q1.4 (D), R2.2, U2.7 (VIN)
unnamed: TP17.1, U3.8 (ST)
unnamed: C26.1, R22.1, SW2.2, U8.2 (EN)
unnamed: R27.1, R28.2, U8.17 (IO1)
unnamed: R19.2, U8.16 (IO2)
unnamed: R20.2, R21.2, U8.3 (IO4)
unnamed: R16.2, U8.7 (IO8)
unnamed: TP3.1, U8.11 (IO20/RXD)
unnamed: R23.2, TP5.1, U8.12 (IO21/TXD)

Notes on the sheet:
Reverse polarity protection
LEDs
3.3v Reg
Filters
Sizé pour 11A
Control
Battery
Static protection
←Output←
Decouplage sortie du boost
Boost converter
MCU_ESP32_C3 WROOM-02(WIFI)
Charger safety bypass :)
Valider res USB
USB
Connectors
Motors
MCU Power selector
Power
Charger
→Input→
Liste des updates pour la V2: - Refaire bien le circuit de switching du power du Buck Vraiment besoin de switcher? Cb de courant les servo prennent si ils ont pas de signal? - Bien sizer les mosfet qui switch le courant - Mettre les LEDs sur 3v3 - Faire en sorte que le board puisse être programmé s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
Implications prog de la V2 - Quand on veut utiliser les servos, on envoie high sur enable du boost - Dès qu'on détecte que l'USB est branché on désactive les servos (pu de PWM) et le enable du boost

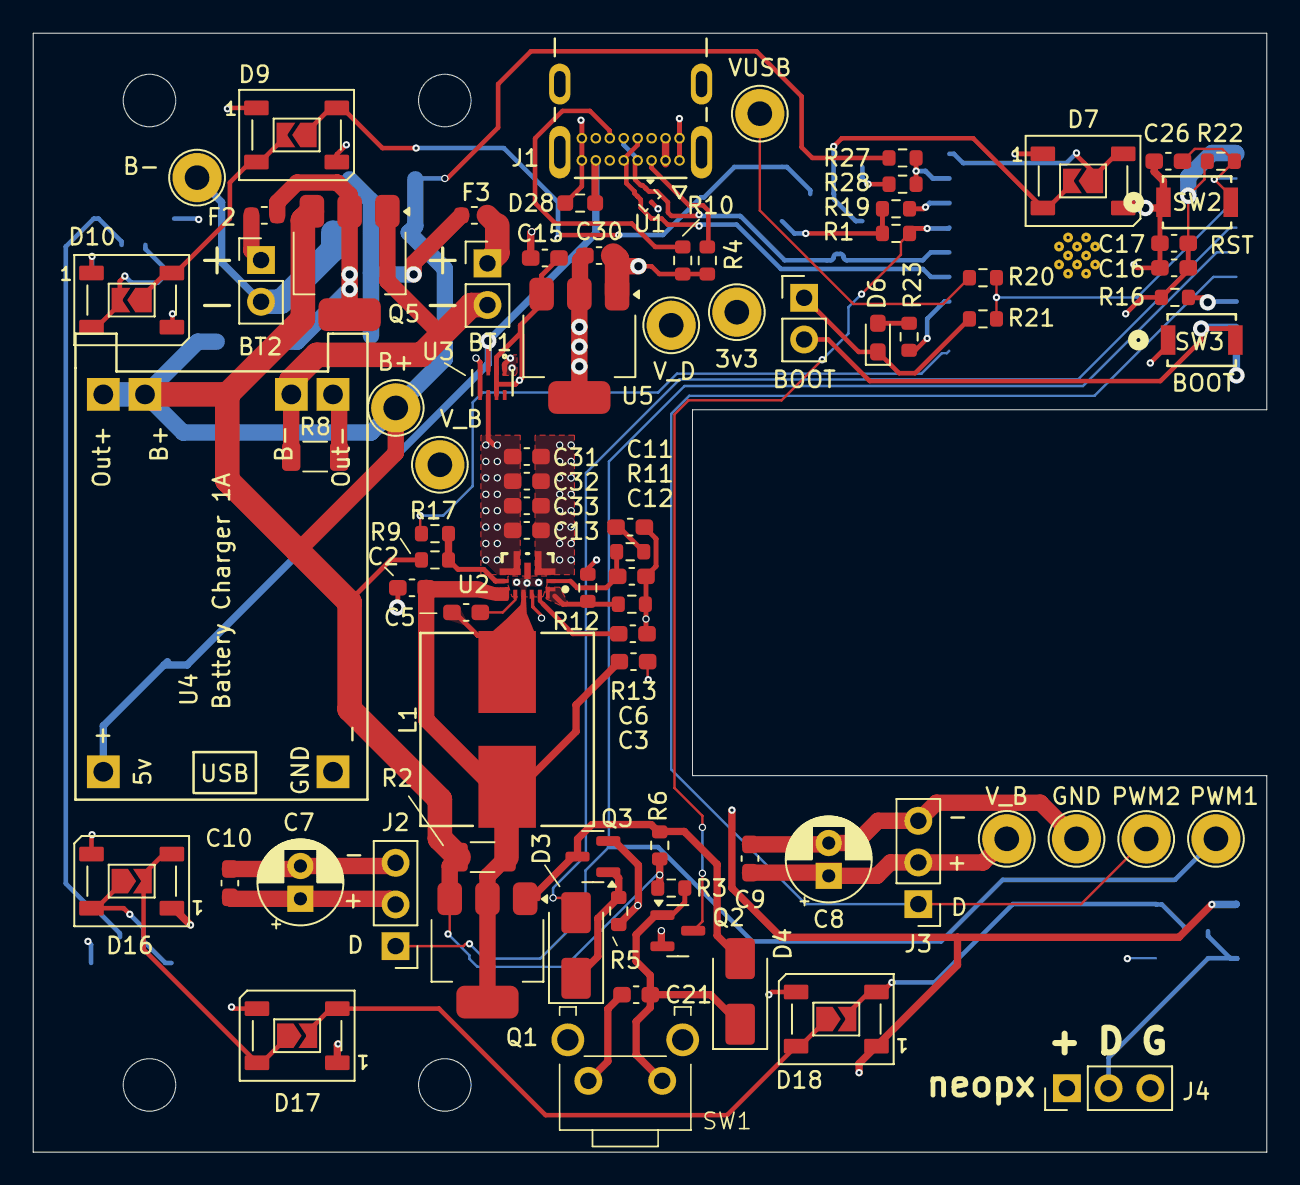
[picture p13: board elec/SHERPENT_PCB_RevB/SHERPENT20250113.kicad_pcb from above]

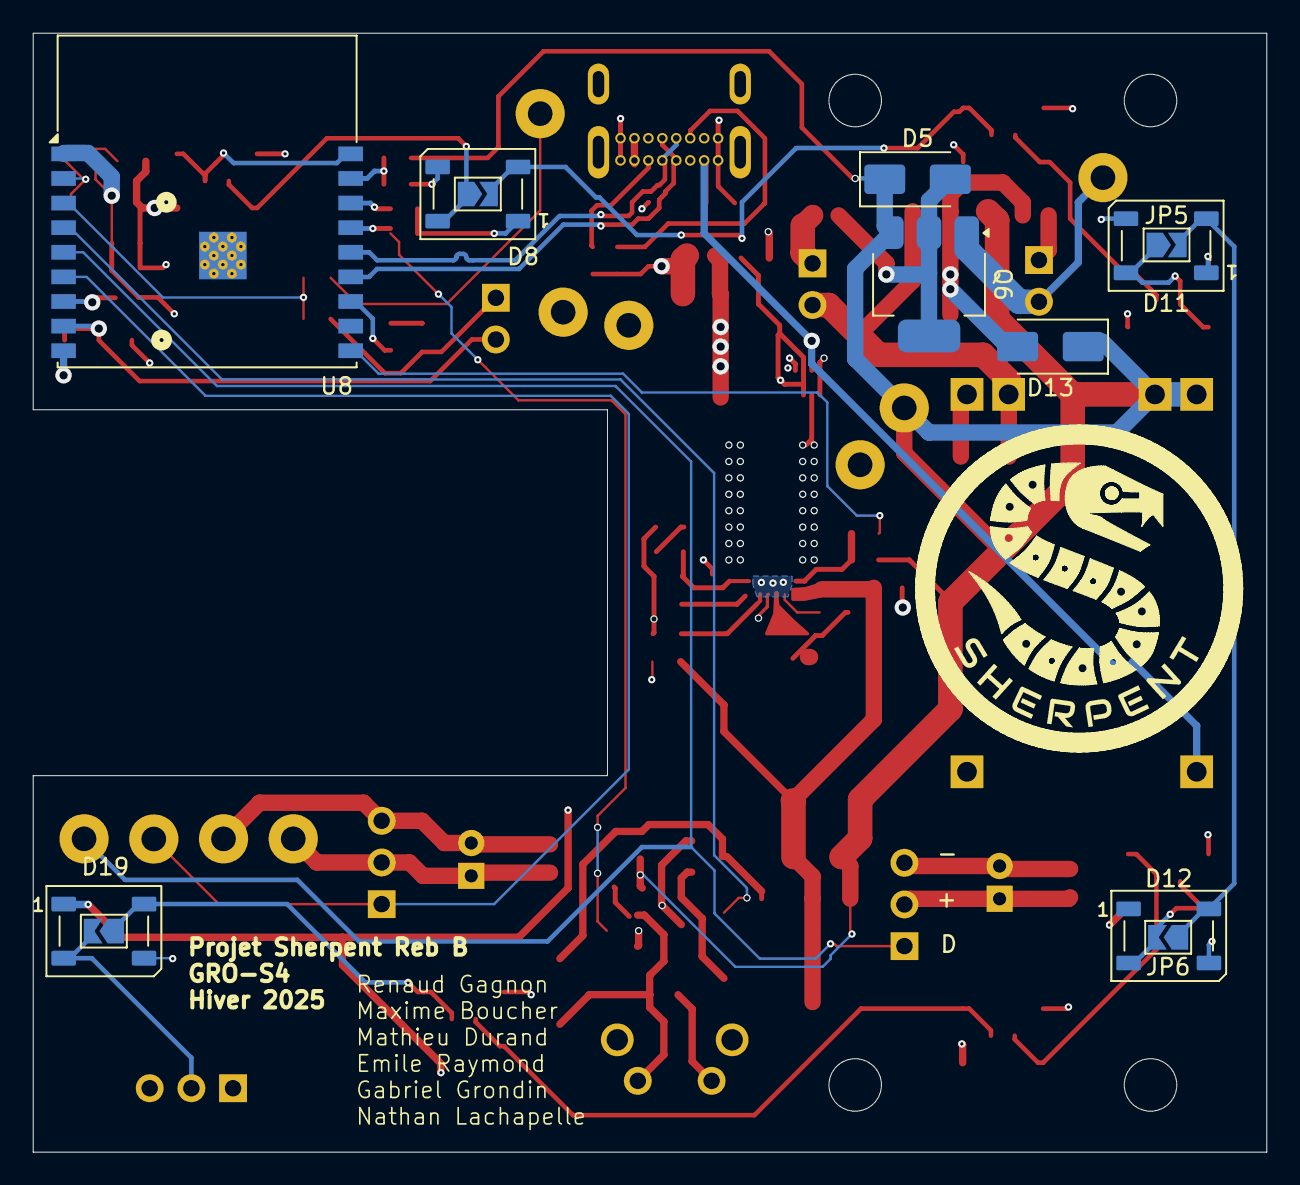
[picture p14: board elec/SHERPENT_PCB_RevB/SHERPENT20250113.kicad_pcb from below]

Board: 4 copper layers, 75.2 x 68.2 mm, 105 parts (12 on the bottom side), 51 nets.

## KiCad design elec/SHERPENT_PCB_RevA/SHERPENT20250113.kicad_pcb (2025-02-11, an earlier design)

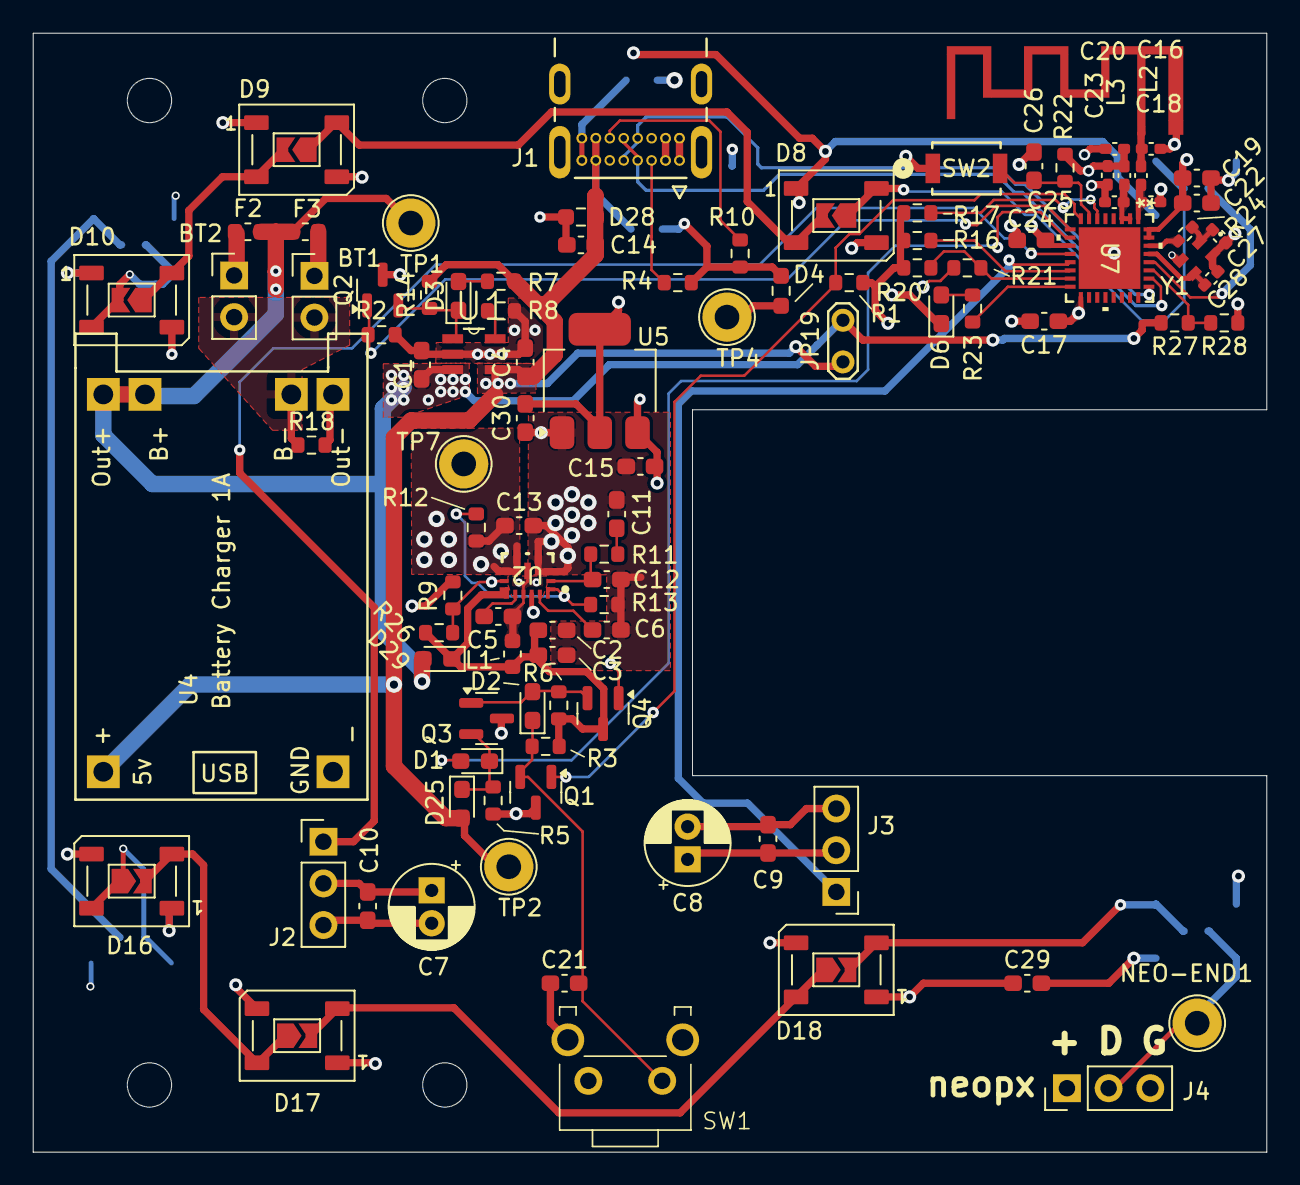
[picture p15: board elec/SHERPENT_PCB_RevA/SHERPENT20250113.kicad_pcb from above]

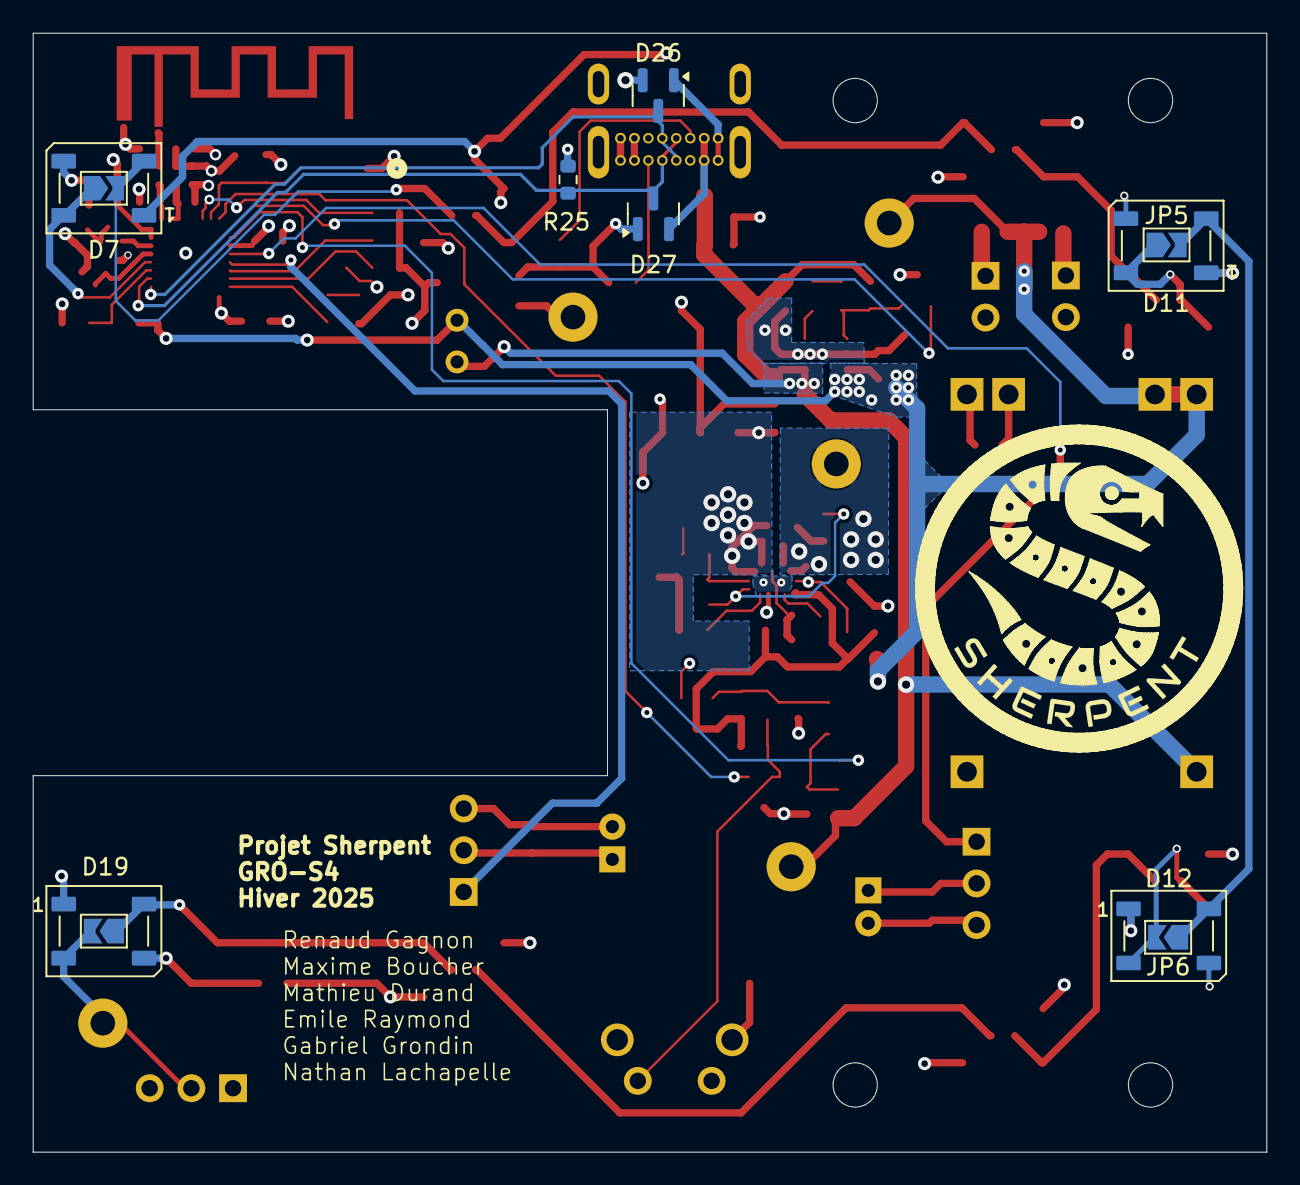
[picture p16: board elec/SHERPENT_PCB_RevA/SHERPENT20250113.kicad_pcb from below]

Board: 4 copper layers, 75.2 x 68.2 mm, 120 parts (11 on the bottom side), 55 nets.

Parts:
BT1, BT2: Battery_Cell; PinHeader_1x02_P2.54mm_Vertical
C1, C4: 4.7u; C_0603_1608Metric_Pad1.08x0.95mm_HandSolder
C2, C15: 10u; C_0603_1608Metric_Pad1.08x0.95mm_HandSolder
C3, C14, C17, C21, C24: 100n; C_0603_1608Metric_Pad1.08x0.95mm_HandSolder
C5: 100nf; C_0603_1608Metric_Pad1.08x0.95mm_HandSolder
C6: 2.2u; C_0603_1608Metric_Pad1.08x0.95mm_HandSolder
C7, C8: 100u; CP_Radial_D5.0mm_P2.00mm
C9, C10, C22, C29: 1u; C_0603_1608Metric_Pad1.08x0.95mm_HandSolder
C11: 39n; C_0603_1608Metric_Pad1.08x0.95mm_HandSolder
C12: 100p; C_0603_1608Metric_Pad1.08x0.95mm_HandSolder
C13: 47u; C_0603_1608Metric_Pad1.08x0.95mm_HandSolder
C16, C18: 1.8p; C_0402_1005Metric_Pad0.74x0.62mm_HandSolder
C19, C26: 10n; C_0603_1608Metric_Pad1.08x0.95mm_HandSolder
C20: 10u; C_0402_1005Metric_Pad0.74x0.62mm_HandSolder
C23: 100n; C_0402_1005Metric_Pad0.74x0.62mm_HandSolder
C25: 1u; C_0402_1005Metric_Pad0.74x0.62mm_HandSolder
C27, C28: 15p; C_0402_1005Metric_Pad0.74x0.62mm_HandSolder
C30: 100u; C_0603_1608Metric_Pad1.08x0.95mm_HandSolder
D1, D2, D25: D_Schottky; LED_0603_1608Metric_Pad1.05x0.95mm_HandSolder
D3, D6: LED; LED_0603_1608Metric_Pad1.05x0.95mm_HandSolder
D4, D28: D_Zener; R_0603_1608Metric_Pad0.98x0.95mm_HandSolder
D7, D8, D9, D10, D11, D12, D16, D17, D18, D19: WS2812B; LED_WS2812B_PLCC4_5.0x5.0mm_P3.2mm
D26, D27: BAV99; SOT-23
D29: D; D_0603_1608Metric_Pad1.05x0.95mm_HandSolder
F2, F3: 10A; Fuse_0603_1608Metric
H1, H2, H3, H4: MountingHole; MountingHole_2.7mm_M2.5
J1: 2137160001; MOLEX_2137160001
J2, J3, J4: Conn_01x03_Socket; PinHeader_1x03_P2.54mm_Vertical
JP1, JP2, JP3, JP4, JP5, JP6, JP15, JP16, JP17, JP18: SolderJumper_2_Open; SolderJumper-2_P1.3mm_Open_TrianglePad1.0x1.5mm
JP19: Jumper_2_Bridged; TestPoint_2Pads_Pitch2.54mm_Drill0.8mm
L1: 1.2u; L_0603_1608Metric
L2: 2.7n; L_0402_1005Metric_Pad0.77x0.64mm_HandSolder
L3: 2n; L_0402_1005Metric_Pad0.77x0.64mm_HandSolder
NEO-END1: TestPoint; TestPoint_Loop_D2.54mm_Drill1.5mm_Beaded
Q1, Q3: NMOS; SOT-23
Q2, Q4: PMOS; SOT-23
R1, R3, R5, R6, R9, R16, R17, R20, R22, R25: 10k; R_0603_1608Metric
R2, R14: 100k; R_0603_1608Metric
R4, R10: 5.1k; R_0603_1608Metric
R7: 470; R_0603_1608Metric
R8: 2k; R_0603_1608Metric
R11: 45.3k; R_0603_1608Metric
R12: 357k; R_0603_1608Metric
R13: 48.7k; R_0603_1608Metric
R18, R21, R26: 0; R_0603_1608Metric
R23: 130; R_0603_1608Metric
R24: 0; R_0402_1005Metric_Pad0.72x0.64mm_HandSolder
R27: 50k; R_0603_1608Metric
R28: 100k 1%; R_0603_1608Metric
SW1: CT1102; CT1102V3.15F100
SW2: SW_Push; SW_CS1213AG_CRS
TP1: VBATT; TestPoint_Loop_D2.54mm_Drill1.5mm_Beaded
TP2, TP4, TP7: TestPoint; TestPoint_Loop_D2.54mm_Drill1.5mm_Beaded
U1: MCP73831T-2ACI_OT; SOT95P280X145-5N
U2: TPS61288LRQQR; RQQ0011A-MFG
U4: TP4056; TP4056-18650
U5: LD1117S33TR_SOT223; SOT-223-3_TabPin2
U6: AN034_ANTENNA
U7: ESP32-C3; QFN32_5X5_EXP-L
Y1: 40MHz; SMD_059627_WRE-L

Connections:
+3.3V: C17.1, C19.1, C20.1, C22.1, C23.1, C24.1, C30.2, D4.1 (K), L3.1, Q2.3 (S), R1.1, R16.1, R17.2, R20.2, R22.2, R25.1, TP4.1, U5.2 (VO), U7.11 (VDD3P3_RTC), U7.17 (VDD3P3_CPU), U7.31 (VDDA), U7.32 (VDDA)
+9V: C7.1, C8.1, C9.1, C10.1, C13.1, C15.1, C29.1, D7.1 (VDD), D8.1 (VDD), D9.1 (VDD), D10.1 (VDD), D11.1 (VDD), D12.1 (VDD), D16.1 (VDD), D17.1 (VDD), D18.1 (VDD), D19.1 (VDD), J2.2, J3.2, J4.1, R12.1, TP7.1, U2.5 (VOUT), U5.3 (VI)
/B-: BT1.2 (-), BT2.2 (-), R18.1, U4.6 (B-)
/Button: Q1.1 (D), R1.2, U7.8 (GPIO3)
/CHARGE: Q2.1 (D), R2.2, U7.9 (MTMS)
/Moteur1_PWM: J2.1, U7.12 (MTCK)
/Moteur2_PWM: J3.1, U7.13 (MTDO)
/NEOPX: D7.4 (DIN), JP1.1 (A), U7.28 (U0TXD)
/NEO_Row2: D12.2 (DOUT), D16.4 (DIN), JP6.2 (B), JP18.1 (A)
/StayOn: D1.2 (A), U7.10 (MTDI)
/USB_ESP32N: D26.3 (K), J1.A7 (DA-), J1.B7 (DB-), U7.25 (GPIO18)
/USB_ESP32P: D27.3 (K), J1.A6 (DA+), J1.B6 (DB+), R25.2, U7.26 (GPIO19)
/VBATT: C1.1, D29.2 (A), F2.2, F3.2, JP19.2 (B), R27.2, TP1.1, U1.3 (VBAT), U4.3 (Out+), U4.5 (B+)
/VUSB: C4.1, C14.1, D25.2 (A), D26.2 (A), D27.2 (A), D28.1 (K), J1.A4 (VBUS1), J1.A9 (VBUS2), J1.B4 (VBUS3), J1.B9 (VBUS4), JP19.1 (A), R7.2, R14.2, TP2.1, U1.4 (VDD), U4.1 (5V_IN)
/neo_end: D19.2 (DOUT), J4.2, JP15.2 (B), NEO-END1.1
GND: C1.2, C2.2, C3.2, C4.2, C6.2, C7.2, C8.2, C9.2, C10.2, C11.2, C12.2, C13.2, C14.2, C15.2, C16.2, C17.2, C18.2, C19.2, C20.2, C21.1, C22.2, C23.2, C24.2, C25.2, C26.2, C27.2, C28.1, C29.2, C30.1, D4.2 (A), D6.1 (K), D7.3 (VSS), D8.3 (VSS), D9.3 (VSS), D10.3 (VSS), D11.3 (VSS), D12.3 (VSS), D16.3 (VSS), D17.3 (VSS), D18.3 (VSS), D19.3 (VSS), D26.1 (K), D27.1 (K), D28.2 (A), J1.A1 (GND1), J1.A12 (GND2), J1.B1 (GND3), J1.B12 (GND4), J2.3, J3.3, J4.3, Q1.3 (S), Q3.3 (S), R2.1, R4.1, R5.2, R8.1, R9.2, R10.2, R13.2, R18.2, R21.1, R28.1, SW1.1, SW1.3, SW1.4, SW2.1, U1.2 (VSS), U2.3 (PGND), U2.10 (AGND), U4.2 (GND), U4.4 (Out-), U5.1 (GND), U6.1 (GND), U7.33 (GND), Y1.2, Y1.4
unnamed: BT1.1 (+), F3.1
unnamed: BT2.1 (+), F2.1
unnamed: C5.1, L1.2, U2.4 (SW), U2.9 (SW)
unnamed: C11.1, R11.2
unnamed: C25.1, L3.2, U7.2 (VDD3P3), U7.3 (VDD3P3)
unnamed: C27.1, R24.2, Y1.1
unnamed: D1.1 (K), D25.1 (K), Q3.2 (G), R5.1
unnamed: D2.2 (A), Q3.1 (D), Q4.2 (G), R6.2
unnamed: C21.2, D2.1 (K), Q1.2 (G), R3.2, SW1.2
unnamed: D3.2 (A), R7.1
unnamed: D3.1 (K), Q2.2 (G), R14.1, U1.1 (STAT)
unnamed: D6.2 (A), R23.1
unnamed: D7.2 (DOUT), D8.4 (DIN), JP1.2 (B), JP2.1 (A)
unnamed: D8.2 (DOUT), D9.4 (DIN), JP2.2 (B), JP3.1 (A)
unnamed: D9.2 (DOUT), D10.4 (DIN), JP3.2 (B), JP4.1 (A)
unnamed: D10.2 (DOUT), D11.4 (DIN), JP4.2 (B), JP5.1 (A)
unnamed: D11.2 (DOUT), D12.4 (DIN), JP5.2 (B), JP6.1 (A)
unnamed: D16.2 (DOUT), D17.4 (DIN), JP17.1 (A), JP18.2 (B)
unnamed: D17.2 (DOUT), D18.4 (DIN), JP16.1 (A), JP17.2 (B)
unnamed: D18.2 (DOUT), D19.4 (DIN), JP15.1 (A), JP16.2 (B)
unnamed: C2.1, C3.1, D29.1 (K), L1.1, Q4.3 (S), R3.1, R6.1, R26.1, U2.7 (VIN)
unnamed: J1.A5 (CC1), R4.2
unnamed: J1.B5 (CC2), R10.1
unnamed: Q4.1 (D), R9.1, R26.2, U2.6 (EN)
unnamed: R8.2, U1.5 (PROG)
unnamed: C5.2, U2.8 (BST)
unnamed: C12.1, R11.1, U2.2 (COMP)
unnamed: R12.2, R13.1, U2.1 (FB)
unnamed: C6.1, U2.11 (VCC)
unnamed: C16.1, L2.1, U6.2 (FP)
unnamed: C26.1, R22.1, SW2.2, U7.7 (CHIP_EN)
unnamed: R17.1, U7.6 (GPIO2)
unnamed: R16.2, U7.14 (GPIO8)
unnamed: R20.1, R21.2, U7.15 (GPIO9)
unnamed: R23.2, U7.16 (GPIO10)
unnamed: C18.1, L2.2, U7.1 (LNA_IN)
unnamed: R27.1, R28.2, U7.27 (U0RXD)
unnamed: C28.2, U7.29 (XTAL_N), Y1.3
unnamed: R24.1, U7.30 (XTAL_P)

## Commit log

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2025-01-13 Début du pcb
    [SHERPENT20250113.kicad_pcb, SHERPENT20250113.kicad_sch, TPS7A2633DRVR.step]
2025-01-15 Changement du DCDC pour quelque chose qui fit avec le servo
    [0430452428.stp, MCP73831T-2ACI_OT.step, SHERPENT20250113.kicad_sch]
2025-01-15 Ajout du circuit du buck-boost
    [SHERPENT20250113.kicad_sch]
2025-01-22 Finalisation du schematics pre-révision
    [SHERPENT20250113.kicad_sch]
2025-01-22 Début du layout
    [SHERPENT20250113.kicad_pcb]
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2025-01-22 Layout: circuit ESP finalisé + début du circuit buck-boost
    [SHERPENT20250113.kicad_pcb, SHERPENT20250113.kicad_sch]
2025-01-22 Auto stash before merge of "main" and "origin/main"
    [SHERPENT20250113.kicad_sch]
2025-01-22 chu pas sur de ce que je fais live
    [SHERPENT20250113.kicad_sch]
2025-01-22 Added pcb outline and gitignore
    [SHERPENT20250113.kicad_pcb]
2025-01-22 fini pour ajd
    [SHERPENT20250113.kicad_pcb]
2025-01-23 Réparation d'erreur
    [SHERPENT20250113_MAX_PAS_TOUCHE.kicad_pcb]
2025-01-25 Avancement du circuit des batteries et de contrôle
    [SHERPENT20250113.kicad_pcb, SHERPENT20250113.kicad_sch]
2025-01-26 Ajout des LED sur le pcb
    [SHERPENT20250113.kicad_pcb, SHERPENT20250113.kicad_sch, SHERPENT20250113_MAX_PAS_TOUCHE.kicad_pcb]
2025-01-26 Ajout de step
    [2137160001.stp, SHERPENT20250113.kicad_pcb, SHERPENT20250113.step]
2025-01-27 Changer le connecteur usb de côté
    [SHERPENT20250113.kicad_pcb, SHERPENT20250113.step]
2025-01-27 rough rgb placement
    [SHERPENT20250113.kicad_pcb, SHERPENT20250113.kicad_sch]
2025-01-27 Quicksave. J'ai mis le connecteur du bon bord. Va falloir flipper le trou de place pis recheck le routing. Stayon circuit en cours
    [SHERPENT20250113.kicad_pcb, SHERPENT20250113.kicad_sch]
2025-01-27 StayOn supposé être fonctionnel
    [SHERPENT20250113.kicad_sch]
2025-01-28 shema bo
    [SHERPENT20250113.kicad_sch]
2025-01-28 Amélioration du shema. Layout et routing de tout ce qui manquait sauf leds et bouton. Bonne nuit!
    [SHERPENT20250113.kicad_pcb, SHERPENT20250113.kicad_sch]
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2025-01-29 Ajout de datasheet et changement de LDO
    [SHERPENT20250113.csv, SHERPENT20250113.kicad_pcb, SHERPENT20250113.kicad_sch]
2025-01-29 Bouton placé
    [CT1102V3.85F160.stp, SHERPENT20250113.kicad_pcb, SHERPENT20250113.kicad_sch]
2025-01-30 Tiens max have fun
    [SHERPENT20250113.kicad_pcb, SHERPENT20250113.kicad_sch]
2025-01-30 Changement de place de l'ESP
    [SHERPENT20250113.kicad_pcb, SHERPENT20250113.kicad_sch]
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2025-01-30 PCB finie, il reste le DRC
    [SHERPENT20250113.kicad_pcb, SHERPENT20250113.kicad_sch]
2025-01-31 Vérification de la charge des batterie et début du sizing des via/track
    [SHERPENT20250113.kicad_pcb, SHERPENT20250113.kicad_sch, SHERPENT20250113.step]
2025-01-31 Mise à jour des netclass
    [SHERPENT20250113.kicad_pcb, SHERPENT20250113.kicad_sch]
2025-01-31 Sauvegarde pre-tutorat
    [SHERPENT20250113.kicad_sch]
2025-01-31 Ajout du thermal relief sur le buck dcdc converter
    [SHERPENT20250113.kicad_pcb, SHERPENT20250113.kicad_sch]
2025-02-01 Modification simple sur la layout, buck-boost
    [SHERPENT20250113.kicad_pcb, SHERPENT20250113.kicad_sch]
2025-02-01 Ajout de la lecture de tension des cellules, grosseur des track, intégrité des signaux
    [SHERPENT20250113.kicad_pcb, SHERPENT20250113.kicad_sch]
2025-02-04 Pascal was here
    [SHERPENT20250113.kicad_pcb, SHERPENT20250113.kicad_sch, SHERPENT20250113.step]
2025-02-04 Petites modifs pour le 4mm 3d et export step
    [SHERPENT20250113.step, SHERPENT20250113_3.step]
2025-02-05 DRC ok
    [SHERPENT20250113.kicad_pcb]
2025-02-05 sleep? no! PCB!
    [SHERPENT20250113.kicad_pcb, SHERPENT20250113.kicad_sch, TP4056--3DModel-STEP-684600.STEP]
2025-02-05 qqch
    oui
    [SHERPENT20250113.kicad_pcb]
2025-02-05 Vite! Mon lit m'attend!
    [SHERPENT20250113.kicad_sch]
2025-02-05 Vérification
    [SHERPENT20250113.kicad_pcb, SHERPENT20250113.kicad_sch]
2025-02-05 Changement des cap pour des electrolotique
    [SHERPENT20250113.kicad_sch]
2025-02-05 Renaud, prend le lead
    [SHERPENT20250113.kicad_pcb]
2025-02-05 b- != gnd
    [SHERPENT20250113.kicad_sch]
2025-02-05 Text editor = kicad editor?
    [SHERPENT20250113.kicad_pcb]
2025-02-05 this device complies with part 15 of the fcc rules
    amongoose
    [SHERPENT20250113.kicad_pcb]
2025-02-05 Silkscreen done
    [SHERPENT20250113.kicad_pcb]
2025-02-06 Conn neopx
    [SHERPENT20250113.kicad_pcb, SHERPENT20250113.kicad_sch]
2025-02-06 Gerber générés et PCB envoyé pour la fabrication
    [SHERPENT20250113-B_Cu.gbl, SHERPENT20250113-B_Mask.gbs, SHERPENT20250113-B_Paste.gbp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]
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2025-02-25 Patches à faire (todo)
    [SHERPENT20250113.kicad_sch]
2025-02-25 Explication détaillée des patches
    [SHERPENT20250113.kicad_sch]
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2025-03-19 Debug servo undervoltage (brownout)
    [SHERPENT20250113.kicad_sch]
2025-03-24 Debug mosfet de switching de power
    [SHERPENT20250113.kicad_sch]
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2025-03-28 routing done. Good night.
    [SHERPENT20250113.kicad_pcb, SHERPENT20250113.kicad_sch]
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2025-03-29 Remis la revA dans le repos
    [0430452428.stp, 2137160001.stp, CT1102V3.85F160.stp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]
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2025-04-09 ajouté les part numbers dasn revA
    [SHERPENT20250113.kicad_sch]
2025-04-09 ajouté les part numbers dans revB
    [SHERPENT20250113.kicad_sch]
2025-04-11 Correction d'erreur sur le schéma
    [SHERPENT20250113.kicad_sch]
